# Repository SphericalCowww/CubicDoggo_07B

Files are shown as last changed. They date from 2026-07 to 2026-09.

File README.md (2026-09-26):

# CubicDoggo 07B: Homemade 12-DOF 4-Legged Robot Recipe

Cubic Doggo 07B Wouf is an upgrade of the base <a href="https://github.com/SphericalCowww/CubicDoggo">Cubic Doggo</a>. The goal is to use a stronger servo and improve the structural support to handle the change.

Requirement: installing ROS2 Jazzy on a Raspberry Pi according to [GitHub](https://github.com/SphericalCowww/ROS_init_practice).

## Ingredients

### 3D printing

The 3D printer model Creality K1C is used with the Orcaslicer, but as long as PLA+ can be printed. All the FreeCAD files can be found here: <a href="https://github.com/SphericalCowww/CubicDoggo_07B/tree/main/src/my_robot_description/mesh/CADv2_ST-3215-C018">link</a>.

### Hardware 

| device | models | count | specification |
| - | - | - | - |
| servo motor | Feetech <a href="https://eckstein-shop.de/feetech-st-3215-c018-servo-en">ST-3215-C018</a> | 12 | Max stall torque: 3.0 N*m (at 12.0V, 2.7A). Weight of 55g. Need also corresponding signal wires of various lengths |
| driver board | <a href="https://eckstein-shop.de/WaveShare-Serial-Bus-Servo-Driver-Board-for-ST-SC-Serial-Bus-Servos-EN">servo driver</a> | 2 | Ccontrol and power the servos in daisy chain |
| onboard computer | Raspberry Pi 5 | 1 | For running just IK, a small RAM is sufficient; Pi 4 could be good enough as long as ROS2 Jazzy can be installed | 
| DC-DC step-down converter | Hailege <a href="https://www.amazon.de/Hailege-Module-Step-Down-Supply-Converter/dp/B07XFMMY1F">24V/12V to 5V/5A</a> | 1 | USB Port port to RaspPi,  DC 5.5mm x 2.5mm Male to battery | 
| battery | ZYGY <a href="https://www.amazon.de/dp/B0BB6RMM5Q">11.1V 2000mAh</a> | 2 | They already include protection. Need Charger. Need adapters for: T-plug => XT60 Male => DC 5.5mm x 2.5mm Male. Also recommend [toggle switches](https://www.amazon.de/-/en/gp/product/B0CX8TRQ35) to be soldered on the T-plugs  | 
| capacitor | 1000uF | 2 | rating 25V or higher | 
| bearings | M3 bearing+<a href="https://www.amazon.de/dp/B01M2ZCLKX">spacer</a>, threaded rod, rod-end bearing | 8, 4, 4, 4 | rod length of 60mm to match the leg length; other dimensions can be accomodated by modifying the CAD |
| bolts and nuts | | | M3 screws are used throughout, except where required to accommodate the servos and electronic boards; use locknuts |
| locking washers | [M3](https://www.amazon.de/dp/B09SCQV81D) | | use in case when locknuts are not available; use it along side regular washer: 3D-printed surface => regular washer => locking washer (convex side away from the surface) => bolt |

Other than the M3 screw, one specific requirement is the M2 self-tapping screws, specific to 1cm length given 6mm padding, for the servos. Note that the length matters a lot, screw in 1 mm too much can already damage the servo!

**Soldering requirement:** solder the 1000uF capacitor to the T-plug to screw terminal adapter (for the servo controllers). Watch out for the polarity.

### Power system

  * Daisy chain no more than 3 servos to avoid excessive current
  * T-plugs are soldered to the bottom of the screw terminal of the driver boards. Adding a toggle switch to each of the T-plugs between the driver board and the battery is recommended because the boards don't have power switches. Search for 12V, 20A requirement for the toggle switches.
  * Power the servo controller with the screw terminal to handle ~16 amp current draw. Insert a 1000uF capacitor between rail and ground with correct polarity (shown in the right photo)
  * Also, in the right photo is that the table is covered by a fire blanket in case of electrical shortages/high current during the testing stage
  * The ground between the 2 controllers should be shared when both are connecting the Rasp Pi with USB
  * Power the RaspPi via a ~12V-to-5V DC-DC converter. Don't forget to put Kapton tape to insulate the two boards

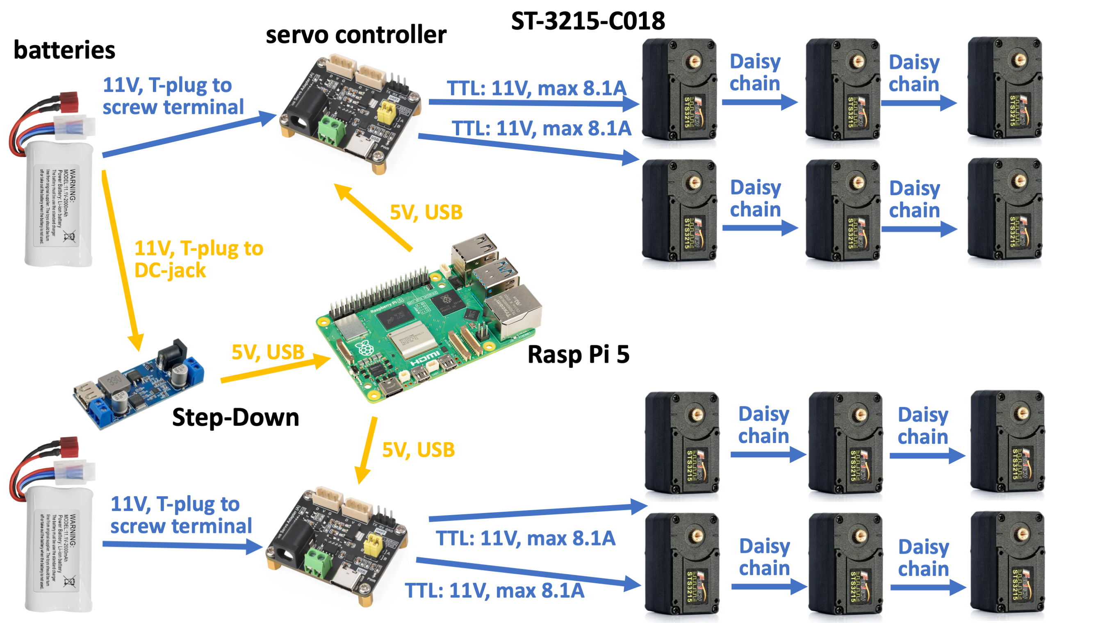
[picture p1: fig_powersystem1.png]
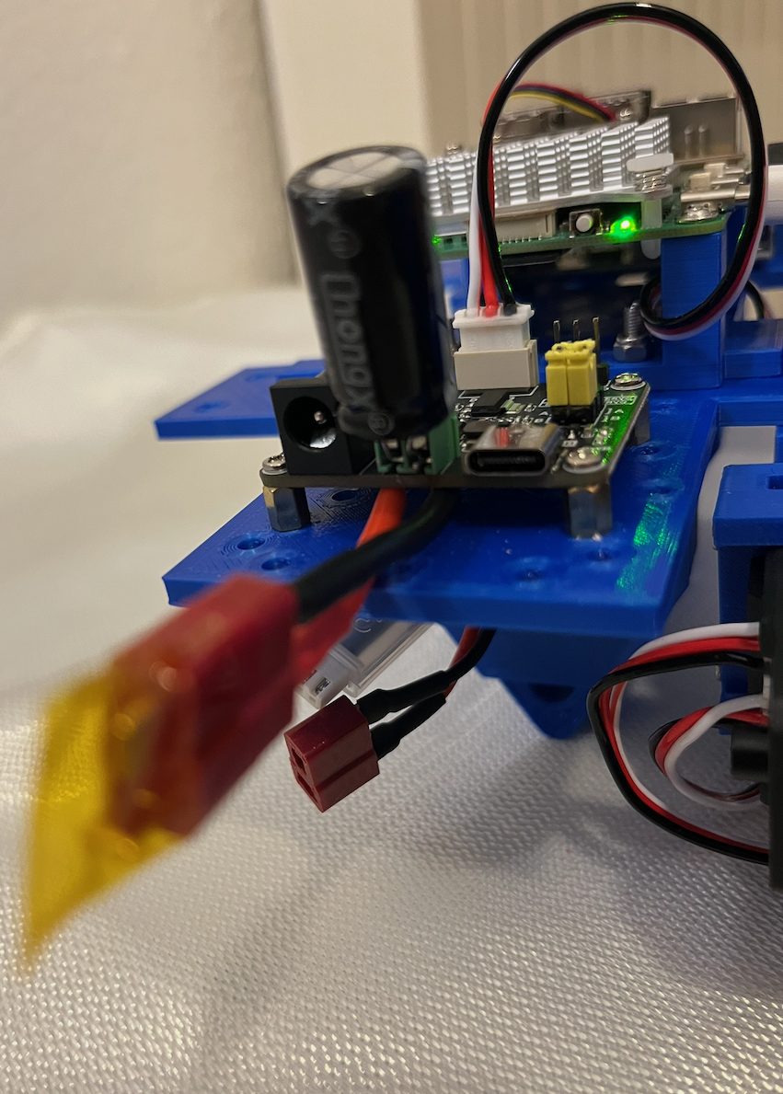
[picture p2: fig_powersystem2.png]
  

## Running servos

### Testing with STServo Python library

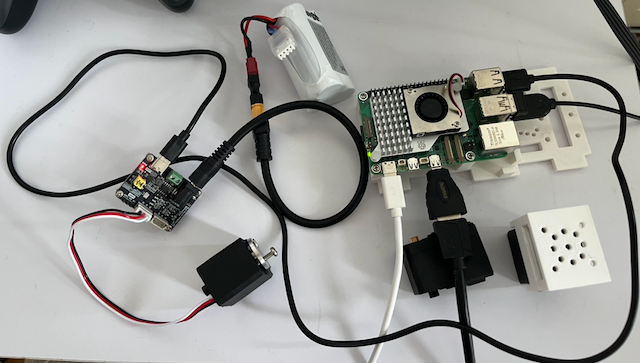
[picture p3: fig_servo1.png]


Plug in the device:

    dmesg | tail -30
    ls -l /dev/ttyACM*                      # or whatever connection is found
    sudo usermod -aG dialout $USER
    sudo reboot

Download ``ST/SC serial bus servo control library (Python)`` from <a href="https://www.waveshare.com/wiki/Bus_Servo_Adapter_(A)">link</a>, put it under ``CubicDoggo_07B/st3215test/``.

    cd CubicDoggo_07B/
    cd ..
    python3 -m venv CubicDoggo_07B_env
    source CubicDoggo_07B_env/bin/activate
    cd CubicDoggo_07B/st3215test/
    unzip STServo_Python.zip
    pip install -r STServo_Python/requirements.txt
    cp -r STServo_Python/stservo-env/scservo_sdk .
    cp STServo_Python/stservo-env/sms_sts/read_write.py test.py    
    vim test.py
    # DEVICENAME = '/dev/ttyUSB0'    # change to the port for the controller
    python3 test.py                  # or spinTest_1servo.py in the code

### Initializing servos in ROS with STServo library

Download ``ST/SC serial bus servo control library (Linux)`` from <a href="https://www.waveshare.com/wiki/Bus_Servo_Adapter_(A)">link</a>, expand it under ``CubicDoggo_07B/src/my_toolbox_scs_workbench/`` and replace ``src/my_toolbox_scs_workbench/SCServo_Linux/SCServo_Linux_220329/SCServo_Linux/CMakeLists.txt``.

    cd CubicDoggo_07B/
    colcon build --packages-select my_toolbox_scs_workbench --cmake-clean-first
    source install/setup.bash

To change the servo ID and initialize the servo, connect only 1 controller and 1 servo,

    vim CubicDoggo_07B/src/my_toolbox_scs_workbench/src/scanUpdateID_zeroing.cpp
    # Modify targetID, EEPROM change is only enabled when ID changes 
    # Modify pos_offset_quick, when settled, set pos_offset_quick=0 and set pos_offset accordingly into the EEPROM
    ros2 run my_toolbox_scs_workbench scanUpdateID_zeroing

Or connect all the servos with IDs listed, update all their EEPROM at once with

    ros2 run my_toolbox_scs_workbench scanUpdateAll_zeroing

**WARNING: DO NOT CTRL-C FOR THESE EEPROM PROCESSES**

Remember to tune and record the pos_offset to set the servo at the correct default position (halfway between minimal and maximal ticks).

To test 1 servo again, do,

    ros2 run my_toolbox_scs_workbench testSpin_servo1

To test 2 servos with 2 controllers, or 3 servos daisy-chained, redo the connection accordingly and do,

    ros2 run my_toolbox_scs_workbench testSpin_servo2controller2
    ros2 run my_toolbox_scs_workbench testSpin_servo3

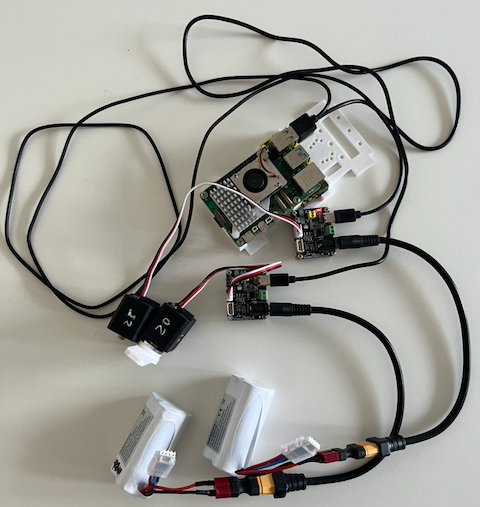
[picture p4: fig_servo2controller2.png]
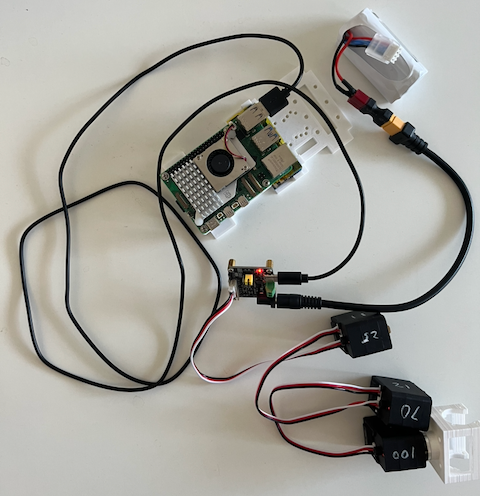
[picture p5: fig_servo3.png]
 

**NOTE:** Record the ``pos_offset`` for each servo independently such that each of their default position is finely aligned.

**NOTE:** ``sts_wb.writeByte``requires unlocking the EEPROM; do NOT do this firmware change too frequently, otherwise it can cause corruption.

## Running a leg

For initial rViz check:

    cd CubicDoggo_07B/
    colcon build
    source install/setup.bash
    ros2 launch my_robot_description cubic_leg1.rviz.launch.xacro.py

For the lifecycle that controls 1 leg:

    # if hardware is not yet connected, use the mock engine
    ## vim CubicDoggo_07B/src/my_robot_description/urdf/cubic_leg1.ros2_control.xacro
    ### uncomment: <!--plugin>mock_components/GenericSystem</plugin-->
    ### comment out: <plugin>cubic_doggo_namespace/HardwareInterfaceST3215_cubic_leg1</plugin>
    cd CubicDoggo_07B/
    colcon build
    source install/setup.bash
    ros2 launch my_robot_bringup cubic_leg1.with_lifecycle.launch.py
    # if no config loaded
    ## Fixed Frame: base_link
    ## Add: RobotModel
    ## RobotModel: Description Topic: /robot_description
    # on another terminal
    ros2 topic pub -1 /leg1_set_named example_interfaces/msg/String "{data: "pose1"}"
    ros2 topic pub -1 /leg1_set_joint example_interfaces/msg/Float64MultiArray "{data: [3.14, 3.14, 3.14]}"
    # record read position 
    ros2 topic pub -1 /leg1_set_pose my_robot_interface/msg/CubicLeg1PoseTarget "{x: 0.09, y: 0.14, z: 0.14, use_cartesian_path: false}"
    ros2 service call /leg1_walk_toggle std_srvs/srv/SetBool "{data: true}"     # IK very easy to fail
    ros2 service call /leg1_walk_toggle std_srvs/srv/SetBool "{data: false}"
    ros2 lifecycle set /cubic_leg1_lifecycle deactivate
    ros2 lifecycle set /cubic_leg1_lifecycle shutdown

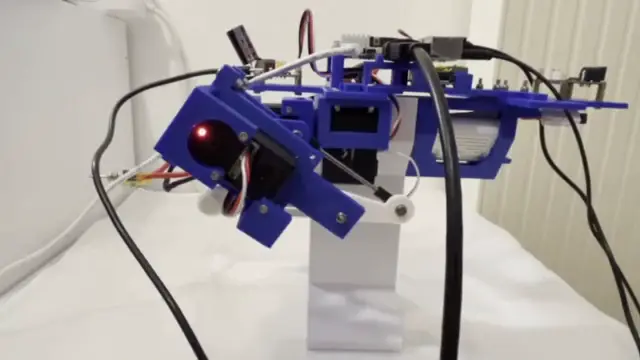
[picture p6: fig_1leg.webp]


## Running the full robot

To check the rViz of the robot:

    cd CubicDoggo_07B/
    colcon build
    source install/setup.bash
    ros2 launch my_robot_description cubic_doggo.rviz.launch.xacro.py

To run the full robot:

    ros2 launch my_robot_bringup cubic_doggo.with_lifecycle.launch.py
    # on another terminal
    ros2 topic pub -1 /leg_set_named example_interfaces/msg/String "{data: "rest"}"
    ros2 topic pub -1 /leg_set_named example_interfaces/msg/String "{data: "stand"}"
    ros2 topic pub -1 /leg_set_named example_interfaces/msg/String "{data: "sit"}"
    ros2 topic pub -1 /leg_set_named example_interfaces/msg/String "{data: "bow"}"
    ros2 topic pub -1 /leg_set_joint example_interfaces/msg/Float64MultiArray "{data: [0, 3.14, 3.14, 3.54]}"
    ros2 topic pub -1 /leg_set_pose my_robot_interface/msg/CubicDoggoLegPoseTarget "{leg_index: 0, x: 0.09, y: 0.14, z: 0.14}" 
    ros2 service call /leg_walk_toggle std_srvs/srv/SetBool "{data: true}"
    ros2 service call /leg_walk_toggle std_srvs/srv/SetBool "{data: false}"

## References:

- Waveshare, <a href="https://www.waveshare.com/wiki/ST3215_Servo">ST3215 Servo</a>, <a href="https://www.waveshare.com/wiki/Bus_Servo_Adapter_(A)">Bus Servo Adapter</a>
- Kitajima, How to Use the ST3215 Servo Motor (<a href="https://www.youtube.com/watch?v=T5T7qCg4pGE">YouTube</a>)
- Kevin McAleer, Why are bus servos better? ([YouTube](https://www.youtube.com/watch?v=nzBZOTdEdtE))

## Acknowledgements

- Libraries and some examples taken from: https://www.waveshare.com/wiki/Bus_Servo_Adapter_(A). The license is not defined.

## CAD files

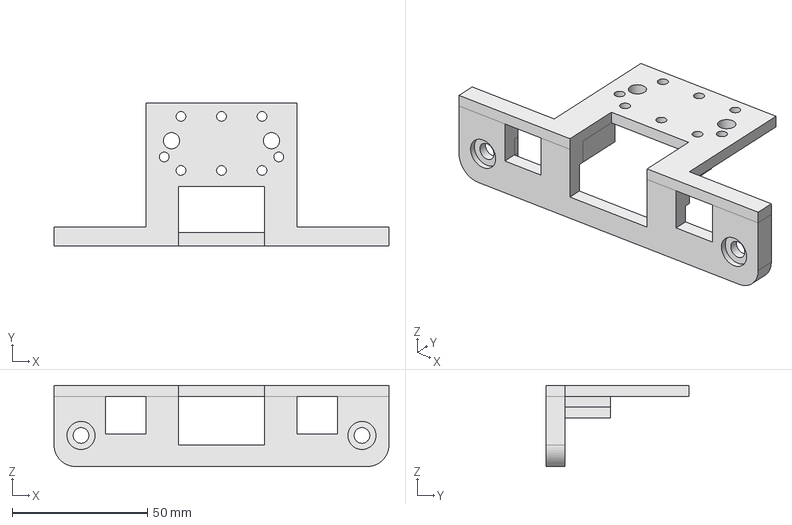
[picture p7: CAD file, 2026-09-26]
src/my_robot_description/mesh/CADv2_ST-3215-C018/bearingPlate.FCStd
124.0 x 53.0 x 30.0 mm

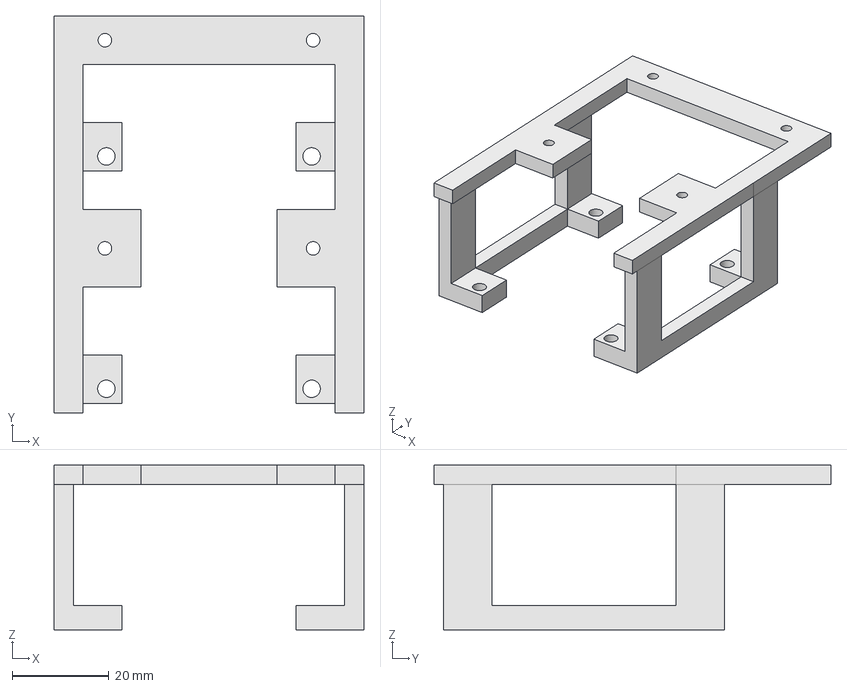
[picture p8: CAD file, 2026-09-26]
src/my_robot_description/mesh/CADv2_ST-3215-C018/lidarHolder.FCStd
64.0 x 82.0 x 34.0 mm

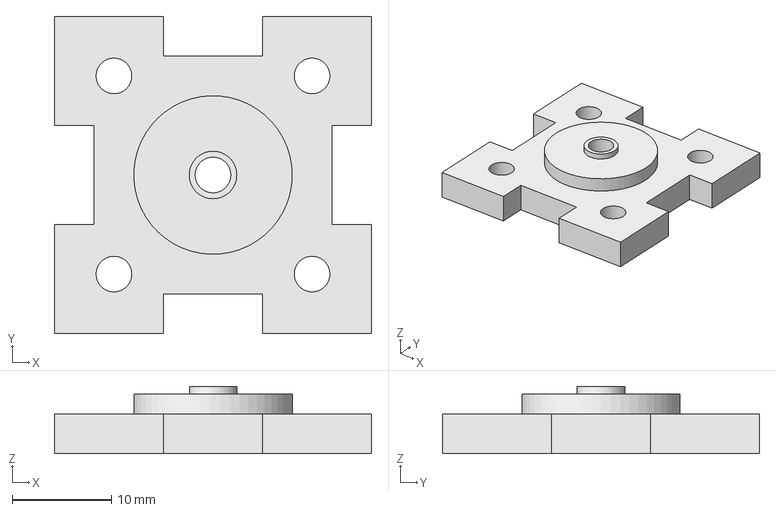
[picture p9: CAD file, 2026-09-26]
src/my_robot_description/mesh/CADv2_ST-3215-C018/bearingPadding.FCStd
32.0 x 32.0 x 6.80 mm

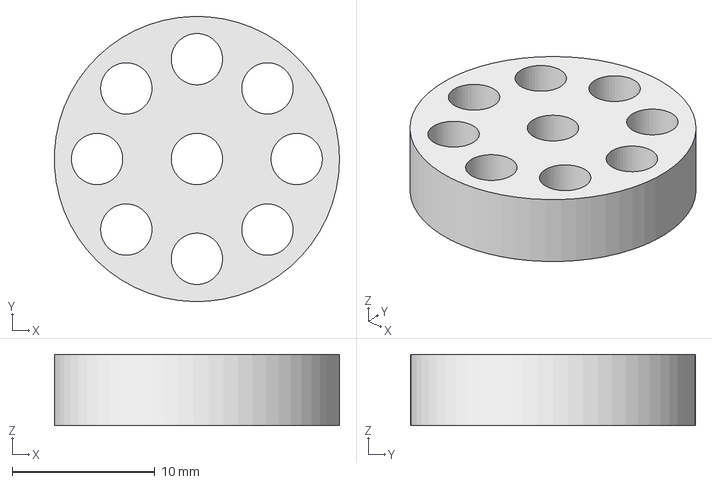
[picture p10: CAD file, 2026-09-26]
src/my_robot_description/mesh/CADv2_ST-3215-C018/ST3215rotorPadding.FCStd
20.0 x 20.0 x 5.00 mm

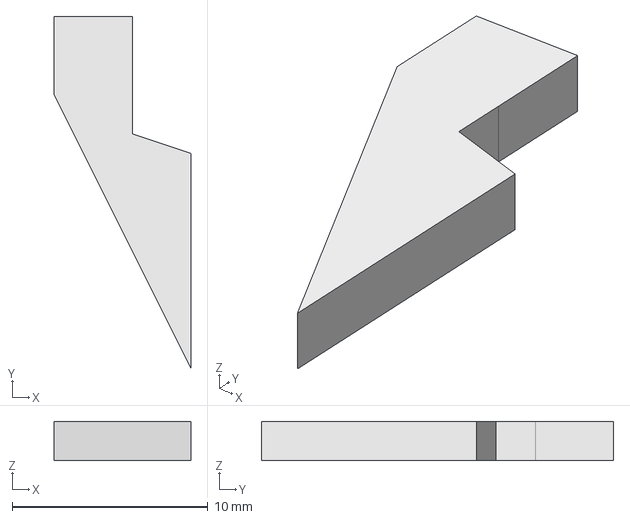
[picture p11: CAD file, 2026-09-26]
src/my_robot_description/mesh/CADv2_ST-3215-C018/ST3215thighFront_GoufBlade.FCStd
7.00 x 18.0 x 2.00 mm

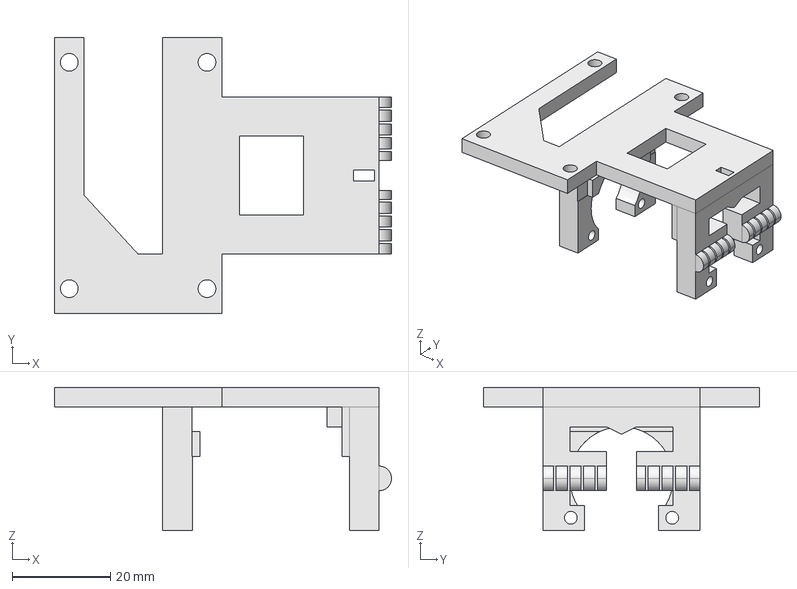
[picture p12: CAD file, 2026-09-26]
src/my_robot_description/mesh/CADv2_ST-3215-C018/ST3215thighFront_Gouf.FCStd
68.5 x 56.0 x 29.1 mm

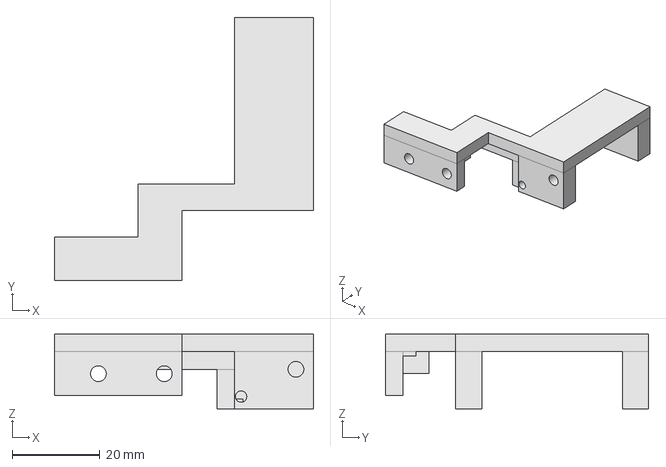
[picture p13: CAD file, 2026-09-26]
src/my_robot_description/mesh/CADv2_ST-3215-C018/ST3215thighBack.FCStd
59.0 x 60.0 x 17.0 mm

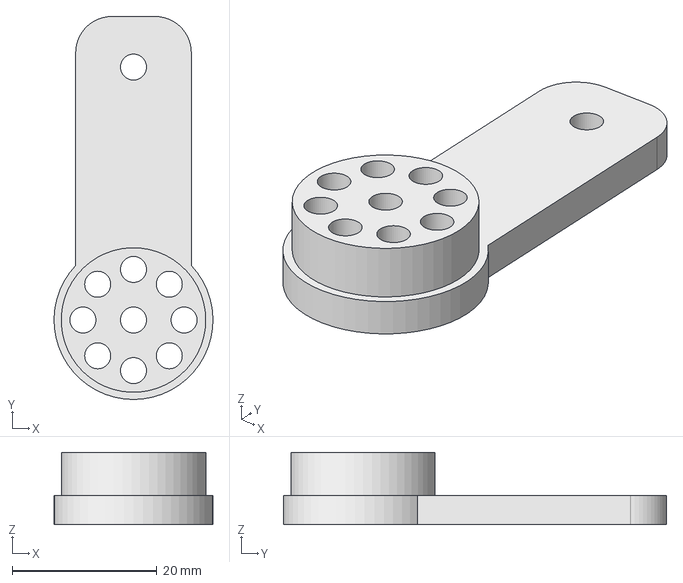
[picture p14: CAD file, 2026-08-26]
src/my_robot_description/mesh/CADv2_ST-3215-C018/ST3215calfJoint.FCStd
22.0 x 53.0 x 10.0 mm

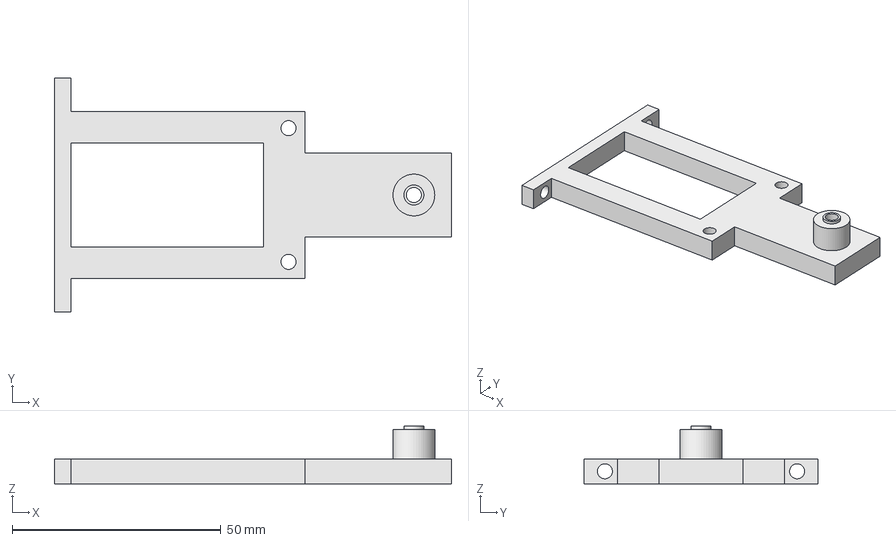
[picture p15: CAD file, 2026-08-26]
src/my_robot_description/mesh/CADv2_ST-3215-C018/ST3215thighOuter.FCStd
95.0 x 56.0 x 13.8 mm

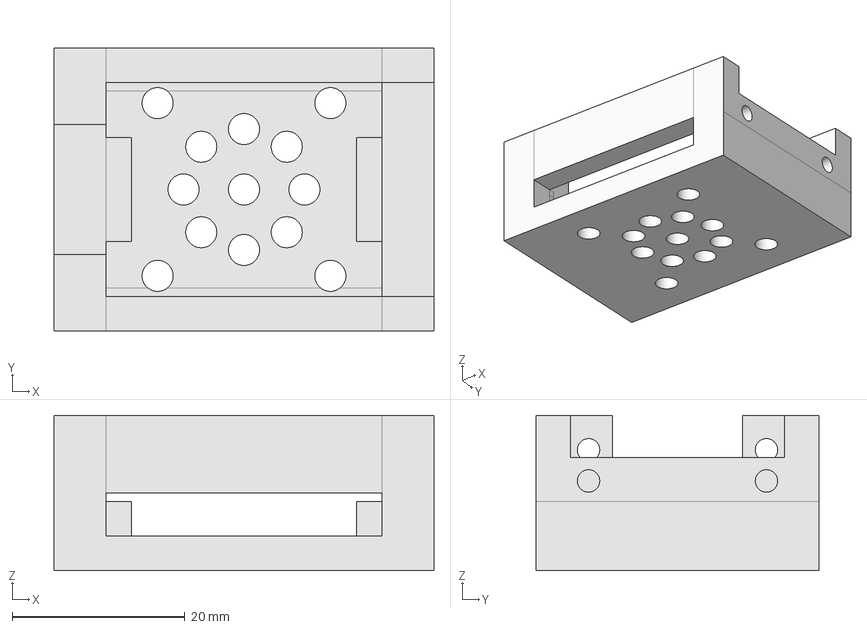
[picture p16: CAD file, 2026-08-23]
src/my_robot_description/mesh/CADv2_ST-3215-C018/ST3215holderBottom.FCStd
44.0 x 32.8 x 18.0 mm

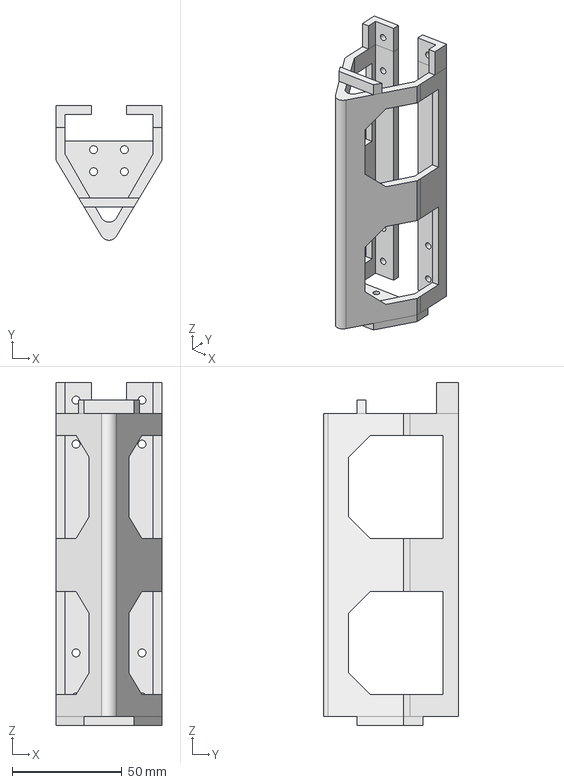
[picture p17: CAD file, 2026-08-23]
src/my_robot_description/mesh/CADv2_ST-3215-C018/batteryHolder.FCStd
48.0 x 61.2 x 156.0 mm

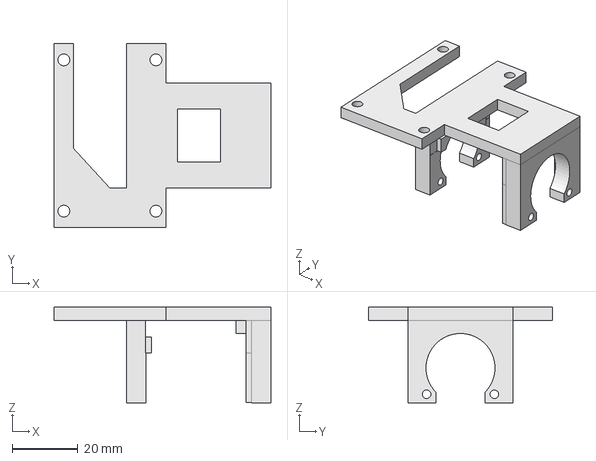
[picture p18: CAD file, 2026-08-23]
src/my_robot_description/mesh/CADv2_ST-3215-C018/ST3215thighFront.FCStd
66.0 x 56.0 x 29.1 mm

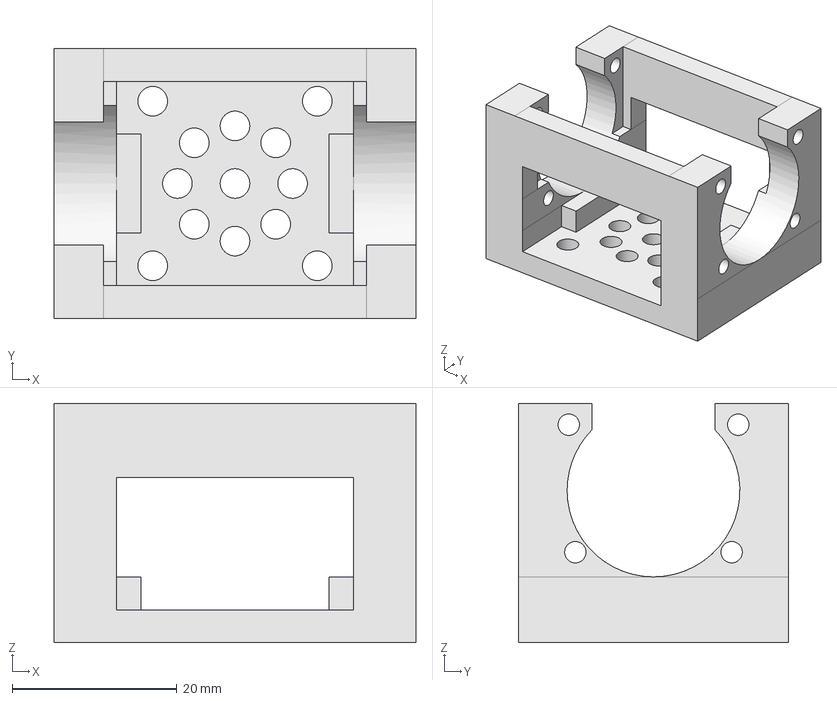
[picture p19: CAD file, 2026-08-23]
src/my_robot_description/mesh/CADv2_ST-3215-C018/ST3215holderTop.FCStd
44.0 x 32.8 x 29.1 mm

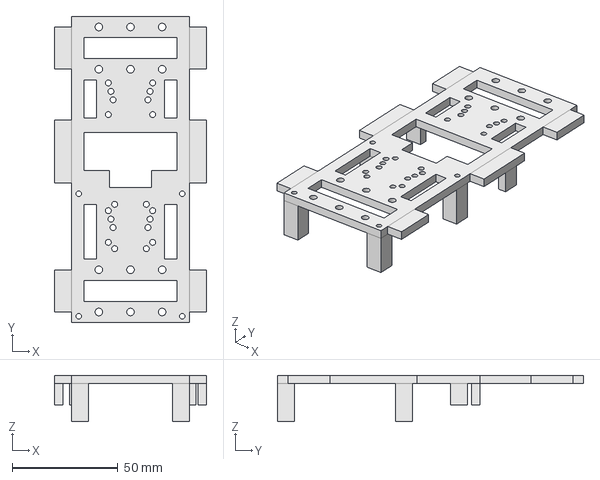
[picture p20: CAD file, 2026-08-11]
src/my_robot_description/mesh/CADv2_ST-3215-C018/baseTorso.FCStd
72.0 x 145.0 x 22.0 mm

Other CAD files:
src/my_robot_description/mesh/CADv2_ST-3215-C018/ST3215thighInner.FCStd
src/my_robot_description/mesh/CADv2_ST-3215-C018/basePlate.FCStd
src/my_robot_description/mesh/CADv2_ST-3215-C018/calfFeet.FCStd
src/my_robot_description/mesh/CADv2_ST-3215-C018/hdmiHolder.FCStd
src/my_robot_description/mesh/CADv2_ST-3215-C018/ST3215calfJoint.stl
src/my_robot_description/mesh/CADv2_ST-3215-C018/ST3215holderBottom.stl
src/my_robot_description/mesh/CADv2_ST-3215-C018/ST3215holderTop.stl
src/my_robot_description/mesh/CADv2_ST-3215-C018/ST3215thighInner.stl
src/my_robot_description/mesh/CADv2_ST-3215-C018/ST3215thighOuter.stl
src/my_robot_description/mesh/CADv2_ST-3215-C018/basePlate.stl
src/my_robot_description/mesh/CADv2_ST-3215-C018/baseTorso.stl
src/my_robot_description/mesh/CADv2_ST-3215-C018/bodyHolder.FCStd
src/my_robot_description/mesh/CADv2_ST-3215-C018/bodyHolderWide.FCStd
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

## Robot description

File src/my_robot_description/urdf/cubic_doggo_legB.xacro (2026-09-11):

<?xml version="1.0"?>
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
<robot xmlns:xacro="http://www.ros.org/wiki/xacro">
    <xacro:macro name="doggo_legB" params="prefix">

    <xacro:property name="servo_x" value="0.02473"/>
    <xacro:property name="servo_y" value="0.04523"/>
    <xacro:property name="servo_z" value="0.035"/>
    <xacro:if value="${prefix == 'BL'}">
        <xacro:property name="rflc" value="-1"/>
        <xacro:property name="base_plate" value='base_plate_B'/>
        <xacro:property name="servo1_holder_xyz" value=" 0.052 0.018 0.004"/>
    </xacro:if>
    <xacro:if value="${prefix == 'BR'}">
        <xacro:property name="rflc" value=" 1"/>
        <xacro:property name="base_plate" value='base_plate_B'/>
        <xacro:property name="servo1_holder_xyz" value="-0.052 0.018 0.004"/>
    </xacro:if> 
    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
    <link name="servo1_holder_${prefix}">
        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
        <xacro:box_inertia m="0.0098" x="0.044" y="0.0328" z="0.012" o_xyz="0 0 0.007" o_rpy="0 0 ${urdf_pi/2}"/>
    </link> 
    <joint name="base_plate_servo1_holder_${prefix}" type="fixed">
        <parent link="${base_plate}"/>
        <child link="servo1_holder_${prefix}"/>
        <origin xyz="${servo1_holder_xyz}" rpy="0 0 0"/>
    </joint>
    
    <link name="servo1_${prefix}">
        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
        <xacro:box_inertia m="0.055" x="${servo_x}" y="${servo_y}" z="${servo_z}" o_xyz="0 0 ${servo_y/2}" o_rpy="${urdf_pi/2} 0 0"/>
    </link> 
    <joint name="servo1_holder_servo1_${prefix}" type="fixed">
        <parent link="servo1_holder_${prefix}"/>
        <child link="servo1_${prefix}"/>
        <origin xyz="0 0 0.008" rpy="0 0 0"/>
    </joint>

    <link name="servo1_padding_${prefix}">
        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
        <xacro:cylinder_inertia m="0.0013" r="0.01" l="0.004" o_xyz="0 -0.002 0" o_rpy="${urdf_pi/2} 0 0"/>
    </link> 
    <joint name="servo1_servo1_padding_${prefix}" type="revolute">
        <parent link="servo1_${prefix}"/>
        <child link="servo1_padding_${prefix}"/>
        <origin xyz="0 ${-servo_z/2-0.002} ${0.01+0.0025/2}" rpy="0 0 0"/>
        <axis xyz="0 -1 0"/>
        <limit effort="1000.0" velocity="50.0" lower="${urdf_pi - urdf_pi/3}" upper="${urdf_pi + urdf_pi/3}"/>
        <dynamics friction="0.05" damping="0.1"/>
    </joint>

    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
    <link name="servo2_holder_${prefix}">
        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
        <xacro:box_inertia m="0.0098" x="0.044" y="0.0328" z="0.012" o_xyz="0 -0.007 0" o_rpy="${urdf_pi/2} 0 0"/>
    </link> 
    <joint name="base_link_servo2_holder_${prefix}" type="fixed">
        <parent link="servo1_padding_${prefix}"/>
        <child link="servo2_holder_${prefix}"/>
        <origin xyz="0 -0.004 0" rpy="0 0 0"/>
    </joint>
    
    <link name="servo2_${prefix}">
        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
        <xacro:box_inertia m="0.055" x="${servo_x}" y="${servo_y}" z="${servo_z}" o_xyz="0 ${-servo_y/2} 0" o_rpy="0 ${rflc*urdf_pi/2} 0"/>
    </link> 
    <joint name="servo2_holder_servo2_${prefix}" type="fixed">
        <parent link="servo2_holder_${prefix}"/>
        <child link="servo2_${prefix}"/>
        <origin xyz="0 -0.008 0" rpy="0 0 0"/>
    </joint>

    <link name="servo2_padding_${prefix}">
        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
        <xacro:cylinder_inertia m="0.0013" r="0.01" l="0.004" o_xyz="${rflc*0.002} 0 0" o_rpy="0 ${urdf_pi/2} 0"/>
    </link> 
    <joint name="servo2_servo2_padding_${prefix}" type="revolute">
        <parent link="servo2_${prefix}"/>
        <child link="servo2_padding_${prefix}"/>
        <origin xyz="${rflc*servo_z/2} -0.01125 0" rpy="0 0 0"/>
        <axis xyz="${rflc} 0 0"/>
        <limit effort="1000.0" velocity="50.0" lower="${urdf_pi - 2*urdf_pi/6 + rflc*urdf_pi/6}" upper="${urdf_pi + 2*urdf_pi/6 + rflc*urdf_pi/6}"/>
        <dynamics friction="0.05" damping="0.1"/>
    </joint>

    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
    <link name="inner_thigh_${prefix}">
        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
        <xacro:box_inertia m="0.0085" x="0.032" y="0.040" z="0.006" o_xyz="${rflc*0.003} -0.016 0" o_rpy="${rflc*urdf_pi/2} 0 ${urdf_pi/2}"/>
    </link>
    <joint name="servo2_padding_inner_thigh_${prefix}" type="fixed">
        <parent link="servo2_padding_${prefix}"/>
        <child link="inner_thigh_${prefix}"/>
        <origin xyz="${rflc*0.004} -0.016 0" rpy="0 0 0"/>
    </joint>

    <link name="outer_thigh_${prefix}">
        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
        <xacro:box_inertia m="0.0113" x="0.040" y="0.032" z="0.006" o_xyz="${rflc*0.003} 0.0475 0" o_rpy="${-urdf_pi/2} ${urdf_pi/2-rflc*urdf_pi/2} ${-rflc*urdf_pi/2}"/>
    </link>
    <joint name="inner_thigh_outer_thigh_${prefix}" type="fixed">
        <parent link="inner_thigh_${prefix}"/>
        <child link="outer_thigh_${prefix}"/>
        <origin xyz="${rflc*0.028} 0 0" rpy="${urdf_pi} 0 0"/>
    </joint>

    <link name="servo3_${prefix}">
        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
        <xacro:box_inertia m="${0.055+0.0113+0.0078}" x="${servo_x}" y="${servo_y}" z="${servo_z}" o_xyz="0 ${-servo_y/2} 0" o_rpy="0 ${rflc*urdf_pi/2} 0"/>
    </link>
    <joint name="outer_thigh_servo3_${prefix}" type="fixed">
        <parent link="outer_thigh_${prefix}"/>
        <child link="servo3_${prefix}"/>
        <origin xyz="${rflc*(servo_y/2-0.006-0.0025)} -0.004 0" rpy="0 0 0"/>
    </joint>

    <link name="calfFeet_${prefix}">
        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
        <xacro:box_inertia m="${0.0251-0.0080}" x="0.110" y="0.016" z="0.004" o_xyz="0 ${-0.008+0.008} ${0.035-0.050}" o_rpy="0 ${-urdf_pi/2} 0"/>
    </link>
    <joint name="servo3_calfFeet_${prefix}" type="revolute">
        <parent link="servo3_${prefix}"/>
        <child link="calfFeet_${prefix}"/>
        <origin xyz="${rflc*(-servo_z/2-0.002-0.0025)} ${-0.086+0.004} 0" rpy="${urdf_pi} 0 0"/>
        <axis xyz="${-rflc} 0 0"/>
        <limit effort="1000.0" velocity="50.0" lower="${5*urdf_pi/8}" upper="${11*urdf_pi/8}"/>
        <dynamics friction="0.0128" damping="0.1"/>
    </joint>

    <link name="calfJoint_${prefix}">
        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
        <xacro:box_inertia m="${0.0047+0.0015}" x="0.022" y="0.053" z="0.007" o_xyz="${-rflc*0.0005} 0 -0.0155" o_rpy="${-urdf_pi/2} ${urdf_pi} ${-rflc*urdf_pi/2}"/>
    </link>
    <joint name="servo3_calfJoint_${prefix}" type="revolute">
        <parent link="servo3_${prefix}"/>
        <child link="calfJoint_${prefix}"/>
        <origin xyz="${rflc*(-servo_z/2-0.002-0.0025)} ${-0.01-0.0025/2-0.001} 0" rpy="0 0 0"/>
        <axis xyz="${-rflc} 0 0"/>
        <mimic joint="servo3_calfFeet_${prefix}" multiplier="1.0" offset="0.0"/>
        <limit effort="1000.0" velocity="50.0" lower="${5*urdf_pi/8}" upper="${11*urdf_pi/8}"/>
        <dynamics friction="0.0212" damping="0.1"/>
    </joint>

    <link name="calfSphere_${prefix}">
        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
        <xacro:sphere_inertia m="0.004" r="0.008" o_xyz="0 0 0" o_rpy="0 0 0"/>
    </link>
    <joint name="calfFeet_calfSphere_${prefix}" type="fixed">
        <parent link="calfFeet_${prefix}"/>
        <child link="calfSphere_${prefix}"/>
        <origin xyz="0.0005 -0.002 ${-0.105+0.035}" rpy="0 0 0"/>
    </joint>
    </xacro:macro>
</robot>
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

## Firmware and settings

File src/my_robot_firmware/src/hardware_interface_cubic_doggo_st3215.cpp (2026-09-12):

#include <iostream>
#include <chrono>
#include <thread>
#include "rclcpp/rclcpp.hpp"
#include "my_robot_firmware/hardware_interface_cubic_doggo_st3215.hpp"

//////////////////////////////////////////////////////////////////////////////////////////////////////////////////////
namespace cubic_doggo_namespace {
    hardware_interface::CallbackReturn HardwareInterfaceST3215_cubic_doggo::on_init(
        const hardware_interface::HardwareComponentInterfaceParams &params) 
    {
        if (hardware_interface::SystemInterface::on_init(params) != hardware_interface::CallbackReturn::SUCCESS) {
            return hardware_interface::CallbackReturn::ERROR;
        }
        RCLCPP_INFO(get_logger(), "hardware_interface:on_init()");

        try {
            port_name_front_ = params.hardware_info.hardware_parameters.at("port_name_front");
            port_name_back_  = params.hardware_info.hardware_parameters.at("port_name_back");
            baud_rate_ = std::stoi(params.hardware_info.hardware_parameters.at("baud_rate"));
        } catch (const std::out_of_range& errorMsg) {
            RCLCPP_ERROR(get_logger(), "hardware_interface:on_init(): missing required parameter in URDF");
            return hardware_interface::CallbackReturn::ERROR;
        }
        RCLCPP_INFO(get_logger(), "hardware_interface:on_init(): st3215 opening port %s and %s at %d baud", 
                                  port_name_front_.c_str(), port_name_back_.c_str(), baud_rate_);
        if (!sts_wb_[0].begin(baud_rate_, port_name_front_.c_str())) {
            RCLCPP_ERROR(get_logger(), "hardware_interface:on_init(): failed to open the port %s!",
                                       port_name_front_.c_str());
            return hardware_interface::CallbackReturn::ERROR;
        }
        if (!sts_wb_[1].begin(baud_rate_, port_name_back_.c_str())) {
            RCLCPP_ERROR(get_logger(), "hardware_interface:on_init(): failed to open the port %s!",
                                       port_name_back_.c_str());
            return hardware_interface::CallbackReturn::ERROR;
        }
        RCLCPP_INFO(get_logger(), "hardware_interface:on_init(): initialize with baud rate: %d", baud_rate_);


        /////////// see: src/my_robot_description/urdf/cubic_doggo.ros2_control.xacro
        servo_channels_[0]  = std::stoi(params.hardware_info.hardware_parameters.at("servo1_channel_FL"));
        servo_channels_[1]  = std::stoi(params.hardware_info.hardware_parameters.at("servo2_channel_FL"));
        servo_channels_[2]  = std::stoi(params.hardware_info.hardware_parameters.at("servo3_channel_FL"));
        servo_channels_[3]  = std::stoi(params.hardware_info.hardware_parameters.at("servo1_channel_FR"));
        servo_channels_[4]  = std::stoi(params.hardware_info.hardware_parameters.at("servo2_channel_FR"));
        servo_channels_[5]  = std::stoi(params.hardware_info.hardware_parameters.at("servo3_channel_FR"));
        servo_channels_[6]  = std::stoi(params.hardware_info.hardware_parameters.at("servo1_channel_BL"));
        servo_channels_[7]  = std::stoi(params.hardware_info.hardware_parameters.at("servo2_channel_BL"));
        servo_channels_[8]  = std::stoi(params.hardware_info.hardware_parameters.at("servo3_channel_BL"));
        servo_channels_[9]  = std::stoi(params.hardware_info.hardware_parameters.at("servo1_channel_BR"));
        servo_channels_[10] = std::stoi(params.hardware_info.hardware_parameters.at("servo2_channel_BR"));
        servo_channels_[11] = std::stoi(params.hardware_info.hardware_parameters.at("servo3_channel_BR"));
        joint_names = {"servo1_servo1_padding_FL", 
                       "servo2_servo2_padding_FL", 
                       "servo3_calfFeet_FL",
                       "servo1_servo1_padding_FR",
                       "servo2_servo2_padding_FR",
                       "servo3_calfFeet_FR",
                       "servo1_servo1_padding_BL",
                       "servo2_servo2_padding_BL",
                       "servo3_calfFeet_BL",
                       "servo1_servo1_padding_BR",
                       "servo2_servo2_padding_BR",
                       "servo3_calfFeet_BR"};
        rad_pos_init_[0]  = 3.14;                      
        rad_pos_init_[1]  = 2.54;                      //M_PI - M_PI/4.0;
        rad_pos_init_[2]  = 4.14;                      //M_PI - M_PI/8.0;
        rad_pos_init_[3]  = 3.14;                      
        rad_pos_init_[4]  = 3.74;                      //M_PI + M_PI/4.0;
        rad_pos_init_[5]  = 2.14;                      //M_PI + M_PI/8.0;
        rad_pos_init_[6]  = 3.14;                     
        rad_pos_init_[7]  = 2.54;                      //M_PI - M_PI/4.0;
        rad_pos_init_[8]  = 4.14;                      //M_PI - M_PI/8.0;
        rad_pos_init_[9]  = 3.14;                      
        rad_pos_init_[10] = 3.74;                      //M_PI + M_PI/4.0;
        rad_pos_init_[11] = 2.14;                      //M_PI + M_PI/8.0;
        ///////////
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

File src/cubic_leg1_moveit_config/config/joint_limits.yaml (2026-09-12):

# joint_limits.yaml allows the dynamics properties specified in the URDF to be overwritten or augmented as needed

# For beginners, we downscale velocity and acceleration limits.
# You can always specify higher scaling factors (<= 1.0) in your motion requests.  # Increase the values below to 1.0 to always move at maximum speed.
default_velocity_scaling_factor: 1.0
default_acceleration_scaling_factor: 1.0

# Specific joint properties can be changed with the keys [max_position, min_position, max_velocity, max_acceleration]
# Joint limits can be turned off with [has_velocity_limits, has_acceleration_limits]
joint_limits:
  servo1_servo1_padding_FL:
    has_velocity_limits: true
    max_velocity: 100.0
    has_acceleration_limits: true
    max_acceleration: 100.0
    has_jerk_limits: true
    max_jerk: 1000.0
  servo2_servo2_padding_FL:
    has_velocity_limits: true
    max_velocity: 100.0
    has_acceleration_limits: true
    max_acceleration: 100.0
    has_jerk_limits: true
    max_jerk: 1000.0
  servo3_calfFeet_FL:
    has_velocity_limits: true
    max_velocity: 100.0
    has_acceleration_limits: true
    max_acceleration: 100.0
    has_jerk_limits: true
    max_jerk: 1000.0
  servo3_calfJoint_FL:
    has_velocity_limits: true
    max_velocity: 100.0
    has_acceleration_limits: true
    max_acceleration: 100.0
    has_jerk_limits: true
    max_jerk: 1000.0

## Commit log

2026-06-21 - changing direction to incorporate ST-3215-C018 setup
    [XL430holderBasic.FCStd, XL430holderBasic.stl, XL430holderThighBack.FCStd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]
2026-07-19 - updating the dimensions for the servo holder
    [XL430holderBasic.FCStd, XL430holderBasic.stl, XL430holderTop.FCStd]
2026-07-19 - more modifications to leave room for connection to the base plate
    [XL430holderTop.FCStd]
2026-07-26 - photo for testing 1 servo
    [XL430holderTop.FCStd]
2026-07-27 - adding the bottom holder (still need to optimize dim), also change name
    [ST3215holderBottom.FCStd, ST3215holderThighBack.FCStd, ST3215holderThighFront.FCStd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]
2026-07-29 - finalizing dimenions for ST3215holderTop/Bottom
    [ST3215holderBottom.FCStd, ST3215holderTop.FCStd]
2026-08-01 - initial update of dimensions for 1 leg
    [ST3215calfJoint.FCStd, ST3215holderBottom.FCStd, ST3215holderThighBack.FCStd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]
2026-08-02 - yet another iteration of updates in dimensions. Still not final
    [ST3215calfJoint.FCStd, ST3215holderBottom.FCStd, ST3215holderTop.FCStd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]
2026-08-07 - more dimensional updates
    [ST3215calfJoint.FCStd, ST3215rotorPadding.FCStd]
2026-08-08 - adding a code to change servo ID
2026-08-08 - now about to run the servo in ROS2
2026-08-09 - more dimensional updated, a few more before fully assembly of 1 leg
    [ST3215holderBottom.FCStd, ST3215thighBack.FCStd, ST3215thighFront.FCStd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]
2026-08-10 - one leg assembly now possible
    [ST3215thighBack.FCStd]
2026-08-11 - simplify battery holder, but may need counter weight towards the front
    [baseTorso.FCStd, batteryHolder.FCStd]
2026-08-20 - c++ code in ros to set servo initial conditions including ID
2026-08-21 - the two controller can simultaneously each drive a servo
2026-08-21 - adding testSpin_servo3.cpp to test 3 servos in a daisy chain
2026-08-23 - make the mount 6mm thick, so that a 1cm self-tapping screw can be used to mount the servos
    [ST3215holderBottom.FCStd, ST3215holderTop.FCStd, ST3215thighBack.FCStd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]
2026-08-23 - initial driver code for st3215
2026-08-26 - more dimension refinements
    [ST3215calfJoint.FCStd, ST3215rotorPadding.FCStd, ST3215thighBack.FCStd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]
2026-08-26 - adding initial files for 1 leg setup
    [cubic_doggo.ros2_control.xacro, cubic_leg1.ros2_control.xacro, cubic_leg1.urdf.xacro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]
2026-09-09 - adding current limit, position mode, and position offset definition under scanUpdateID_zeroing.cpp
2026-09-09 - forgeting to add move_group.launch.py
    [ST3215rotorPadding.FCStd]
2026-09-10 - adding .stl for URDF
    [ST3215calfJoint.stl, ST3215holderTop.stl, ST3215thighInner.stl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]
2026-09-10 - also adding baseTorso.stl
    [baseTorso.stl]
2026-09-10 - adding a bit more .stl
    [ST3215holderBottom.stl, calfFeet.stl]
2026-09-10 - updated the urdf for the new servo dimension
    [cubic_doggo_legB.xacro, cubic_doggo_legF.xacro, cubic_leg1.ros2_control.xacro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]
2026-09-11 - 4 legged URDF also complete
    [cubic_doggo.urdf.xacro, cubic_doggo_legB.xacro, cubic_doggo_legF.xacro]
2026-09-11 - update to run lifecycle for 1 leg
    [cubic_leg1.urdf.xacro, cubic_leg1_controllers.yaml, joint_limits.yaml]
2026-09-11 - debugging interfacing with hardware for 1 leg
    [cubic_doggo.ros2_control.xacro, cubic_leg1.ros2_control.xacro]
2026-09-12 - the 1 leg hardware can now move
2026-09-12 - trying to improve the speed
    [joint_limits.yaml]
2026-09-16 - recording the position offsets for servo 11, 12, and 13
2026-09-17 - update some EEPROM for the initial 4 leg test
2026-09-18 - edited some CAD
    [ST3215thighFront_Gouf.FCStd, bearingPlate.FCStd]
2026-09-18 - more CAD gouf update
    [ST3215thighFront_Gouf.FCStd, ST3215thighFront_GoufBlade.FCStd]
2026-09-19 - edited more gouf CAD
    [ST3215thighFront_Gouf.FCStd, ST3215thighFront_GoufBlade.FCStd, bearingPlate.FCStd]
2026-09-22 - finalizing the CAD dimensions - update dimension for lidar
    [ST3215rotorPadding.FCStd, ST3215thighFront_Gouf.FCStd, bearingPadding.FCStd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]
2026-09-23 - hopefully CAD dim really finalized this time
    [bearingPlate.FCStd, lidarHolder.FCStd]
2026-09-25 - a 1mm correction needs to be reversed after all. Not sure why, but now everything fits!
    [ST3215thighBack.FCStd]
2026-09-26 - initializing all 12 servos, each with their corresponding offsets
2026-10-28 - turning off the read function from servo for now due to latency issue
